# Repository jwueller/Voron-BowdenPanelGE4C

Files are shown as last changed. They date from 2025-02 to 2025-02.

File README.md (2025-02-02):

Low-Profile GE4C Bowden Tube Passthrough for 3 mm Panels
========================================================

This is a from-scratch redesign of ["PTFE/Bowden Tube Passthrough with GE4C Spherical Bearing" by Mark Norris](https://www.printables.com/model/795052-ptfebowden-tube-passthrough-with-ge4c-spherical-be). It retains the same footprint and hole spacing for full compatibility while introducing key improvements.

[View on Printables](https://www.printables.com/model/1174655-low-profile-ge4c-bowden-tube-passthrough-for-3mm-p)

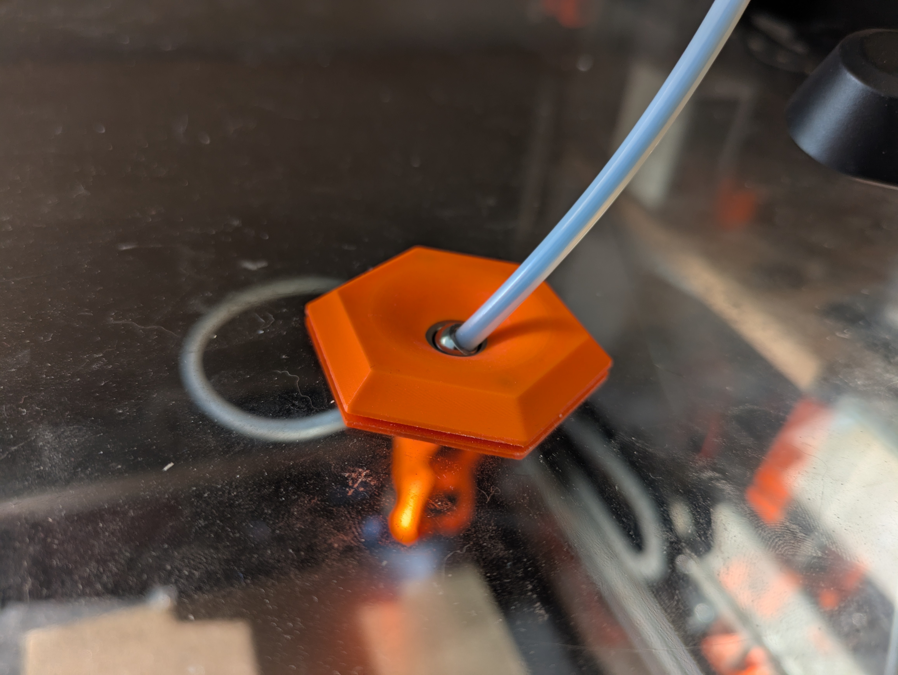
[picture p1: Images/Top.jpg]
Top View

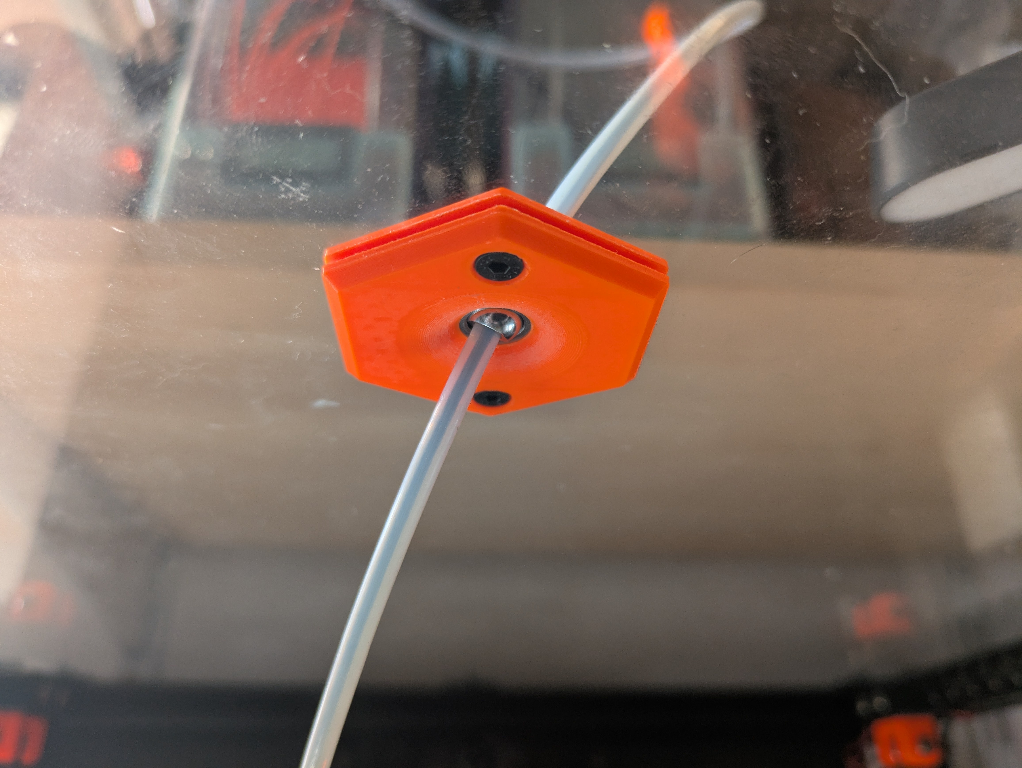
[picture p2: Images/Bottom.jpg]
Bottom View

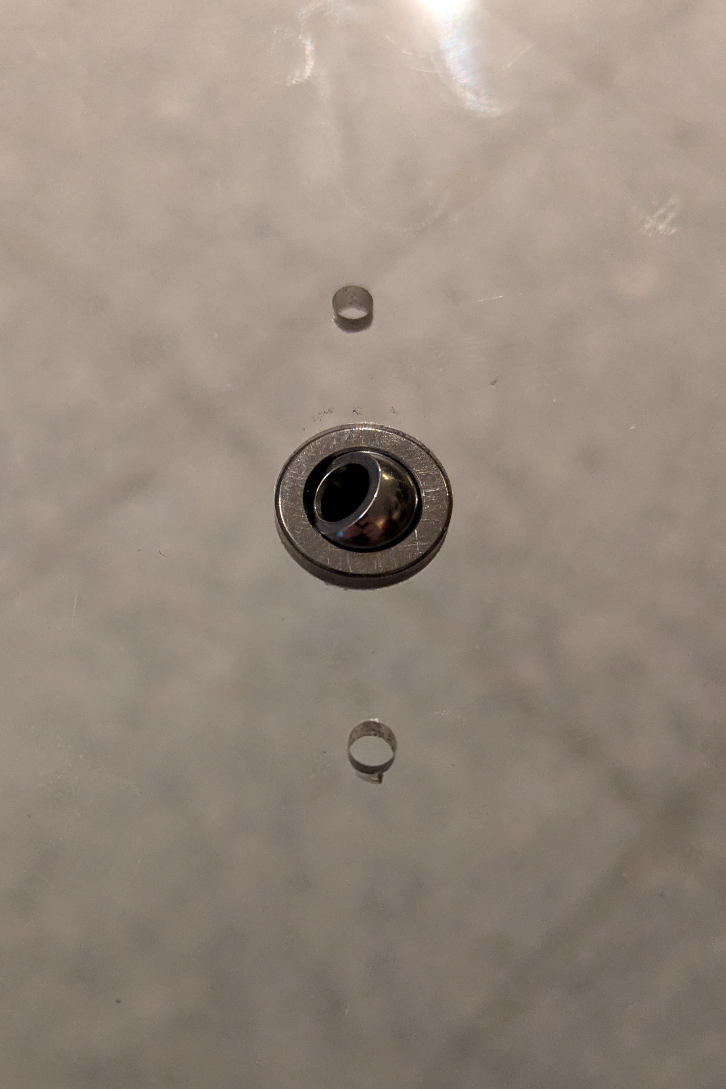
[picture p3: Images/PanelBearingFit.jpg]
Panel Bearing Fit


## Design Goals

- **Full Range of Motion**
  The passthrough is designed for a **12 mm hole** in a **3 mm thick panel**, ensuring that the GE4C spherical bearing's _center of rotation_ is precisely aligned between the inside and outside surfaces. This maximizes the bearing's range of motion.
- **Minimalist Exterior**
  The top half features **heat-set inserts** for M3 screws, ensuring the **outside remains smooth** with no exposed holes.
- **Minimal Interior Profile**
  The bottom half is only **3 mm thick**, keeping it as compact as possible to minimize interference with the Bowden tube inside the enclosure. The other half is slightly thicker to accommodate the heat-set inserts.
- **Smooth Filament Path**
  The edges around the bearing hole are **gradually sloped**, preventing the Bowden tube from catching or kinking when moving against the printed surface.

## BOM

- 1x **GE4C bearing** (i.e. 12x3 mm outer ring dimensions)
- 2x **M3x8 mm FHCS** (but M3x10 mm FHCS should fit too)
- 2x **M3x5x4 mm Heat-set Insert**

## Print Settings

I recommend printing with **standard _Voron_ settings**, but **variable layer height** improves curved surface finish if your slicer supports it. A lower infill density may also work.

- **Layer height**: 0.2mm
- **Extrusion width**: 0.4mm, forced
- **Infill percentage**: 40%
- **Infill type**: grid, gyroid, honeycomb, triangle, or cubic
- **Wall count**: 4
- **Solid top/bottom layers**: 5
- **Supports**: _none_

## Notes

- The halves **are _not_ symmetrical** — be sure to orient them correctly when assembling.
- I recommend making a small pilot hole using the drill template, then using a **stepped drill bit** to gradually widen it to **12 mm** for the best fit.
- A bearing press-fit is optional since the printed halves will secure the bearing, but minimizing lateral play is still recommended.

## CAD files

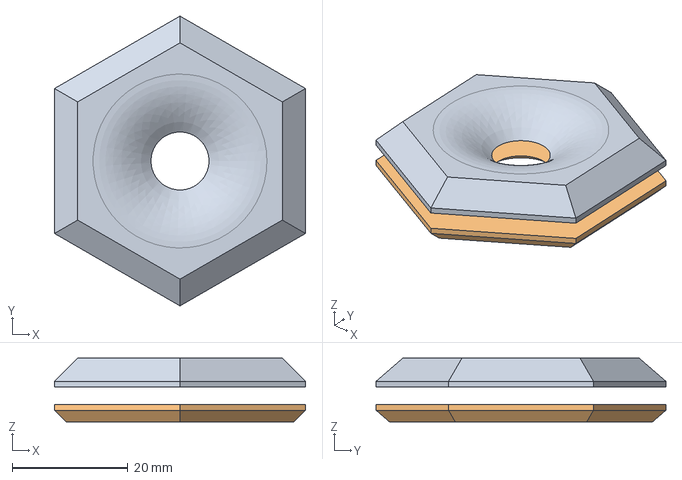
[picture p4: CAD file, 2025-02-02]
CAD/BowdenPanelGE4C.FCStd
43.3 x 50.0 x 11.0 mm
Top
Bottom

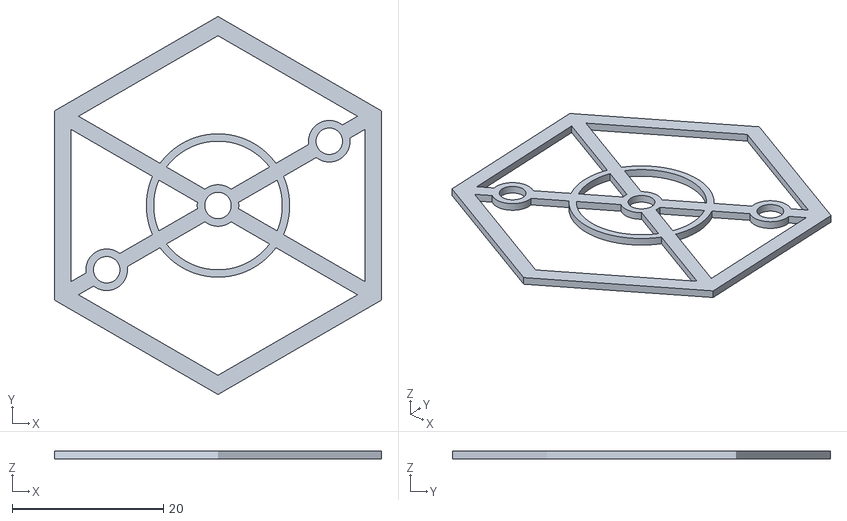
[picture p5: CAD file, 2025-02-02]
STLs/BowdenPanelGE4C-DrillTemplate.stl
43.3 x 50.0 x 1.00

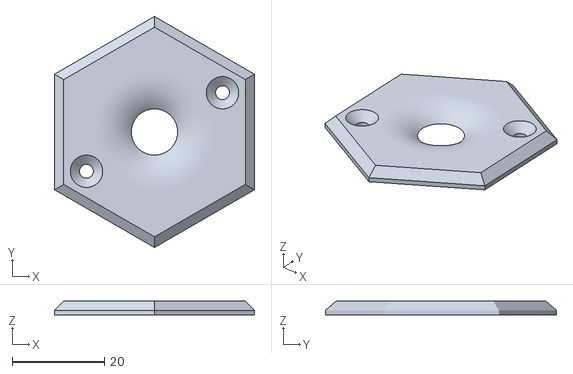
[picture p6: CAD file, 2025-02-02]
STLs/BowdenPanelGE4C-Bottom.stl
43.3 x 50.0 x 3.00

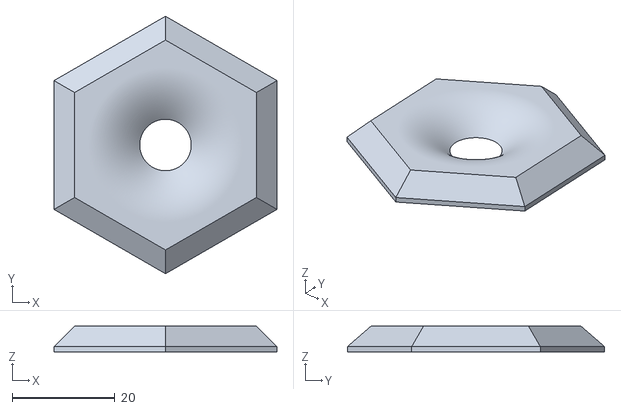
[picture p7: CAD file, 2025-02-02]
STLs/BowdenPanelGE4C-Top.stl
43.3 x 50.0 x 5.00
